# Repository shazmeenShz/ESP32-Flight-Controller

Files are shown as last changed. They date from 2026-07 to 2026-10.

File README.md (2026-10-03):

# ESP32 Flight Controller

<p align="center">
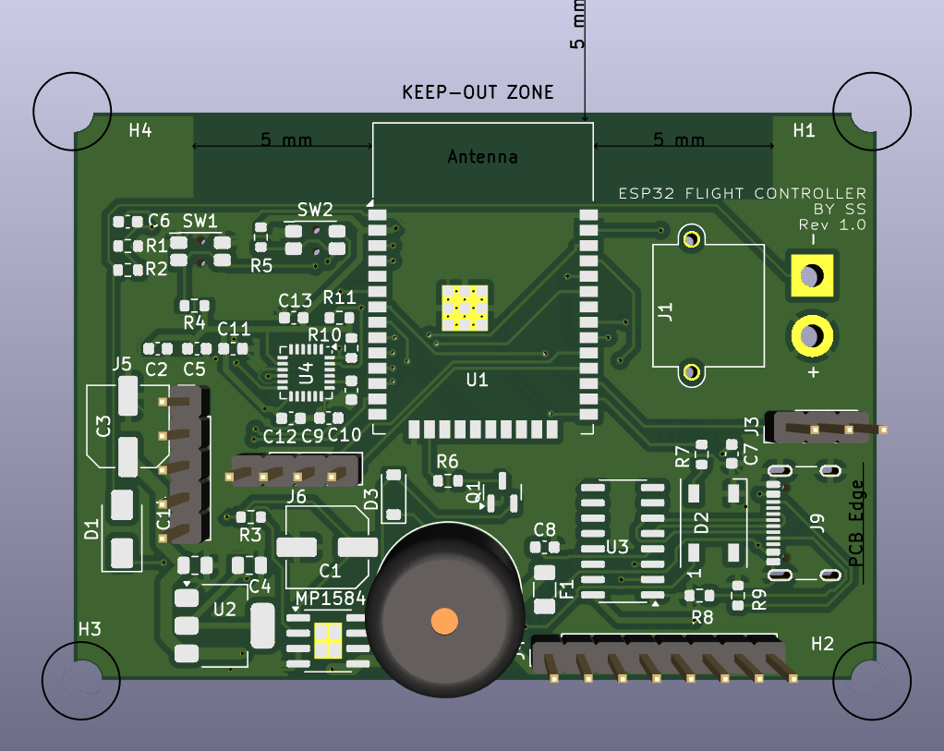
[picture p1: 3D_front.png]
  
</p>

> A custom 4-layer IoT-ready ESP32-based Flight Controller designed in KiCad 8 for UAV and robotics applications.






---

# Overview

This project is a custom-designed 4-layer ESP32-based Flight Controller PCB developed in KiCad 8. Built around the ESP32-WROOM-32E, the board integrates power management, sensor interfaces, USB programming, and wireless connectivity capabilities, making it suitable for UAVs, robotics, and IoT-enabled embedded systems.

The design follows industry-standard PCB practices, including dedicated ground and power planes, RF antenna keep-out, proper decoupling, and comprehensive Design Rule Checking (DRC), resulting in a manufacturing-ready hardware platform.

---

# Applications

- UAV & Drone Flight Controllers
- IoT-enabled Robotics
- Wireless Sensor Nodes
- Remote Monitoring Systems
- Autonomous Embedded Platforms
- Research & Academic Projects
- Rapid Prototyping for Embedded Systems

---

# Features

- ESP32-WROOM-32E Microcontroller
- Wi-Fi & Bluetooth Enabled (ESP32)
- IoT-Ready Embedded Hardware Platform
- 4-Layer PCB Design
- USB Type-C Programming Interface
- CH340C USB-to-UART Converter
- MP1584 Buck Converter (Battery to 5V)
- AMS1117-3.3V Linear Regulator
- MPU6050 6-Axis IMU Interface
- GPS UART Interface
- SBUS/iBUS Receiver Interface
- Battery Voltage Monitoring
- WS2812B Addressable RGB Status LED
- Active Buzzer Interface
- Boot & Reset Buttons
- Mounting Holes
- RF Antenna Keep-Out Zone
- Ground and Power Copper Planes
- DRC Clean (0 Errors, 0 Warnings)

---

# Hardware Specifications

| Parameter | Specification |
|---|---|
| MCU | ESP32-WROOM-32E |
| PCB Layers | 4 |
| Power Input | LiPo Battery |
| Buck Converter | MP1584 |
| LDO Regulator | AMS1117-3.3V |
| USB Interface | USB Type-C |
| USB-UART | CH340C |
| IMU | MPU6050 |
| Receiver | SBUS / iBUS |
| GPS | UART |
| Battery Monitor | Voltage Divider |
| Status Indicator | WS2812B RGB LED |
| Buzzer | Active Buzzer |
| CAD Software | KiCad 8 |

---

# PCB Stack-Up

Layer 1
```
Top Signal Layer
```

Layer 2
```
Ground Plane
```

Layer 3
```
Power Plane
```

Layer 4
```
Bottom Signal Layer
```

---

# Power Architecture

```
LiPo Battery
      │
      ▼
   MP1584
 (Buck Converter)
      │
      ▼
      5V
      │
      ▼
 AMS1117-3.3V
      │
      ▼
     ESP32
```

---

# Interfaces

| Interface | Purpose |
|---|---|
| USB Type-C | Programming & Power |
| UART | GPS |
| SBUS/iBUS | RC Receiver |
| I²C | MPU6050 |
| ADC | Battery Voltage Monitoring |
| GPIO | WS2812B & Buzzer |

---

# Design Highlights

- Dedicated Ground Plane
- Dedicated Power Plane
- RF Antenna Keep-Out
- Proper Decoupling Capacitors
- Copper Pour Optimization
- Manual PCB Routing
- Differential USB Routing
- Professional Silkscreen
- Optimized Component Placement
- Manufacturing Ready

---

# Design Workflow

- Component Selection
- Schematic Design
- ERC Verification
- Footprint Assignment
- PCB Layout
- Component Placement
- Net Class Assignment
- Manual Routing
- Copper Pour
- DRC Verification
- Gerber Generation

---

# Repository Structure

```
ESP32-Flight-Controller
│
├── Hardware
│   ├── flight_controller.kicad_pro
│   ├── flight_controller.kicad_sch
│   ├── flight_controller.kicad_pcb
│
├── Gerbers
│
├── Images
│   ├── PCB_Top.png
│   ├── PCB_Bottom.png
│   ├── 3D_Top.png
│   ├── 3D_Bottom.png
│   └── Schematic.png
│
├── BOM
│
└── README.md
```

---

# Project Status

- [x] Schematic Design
- [x] PCB Layout
- [x] Footprint Assignment
- [x] 4-Layer PCB
- [x] Manual Routing
- [x] Ground Copper Pour
- [x] Power Copper Plane
- [x] DRC Passed
- [x] Manufacturing Ready

---

# Images

## PCB Layout

<p align="center">
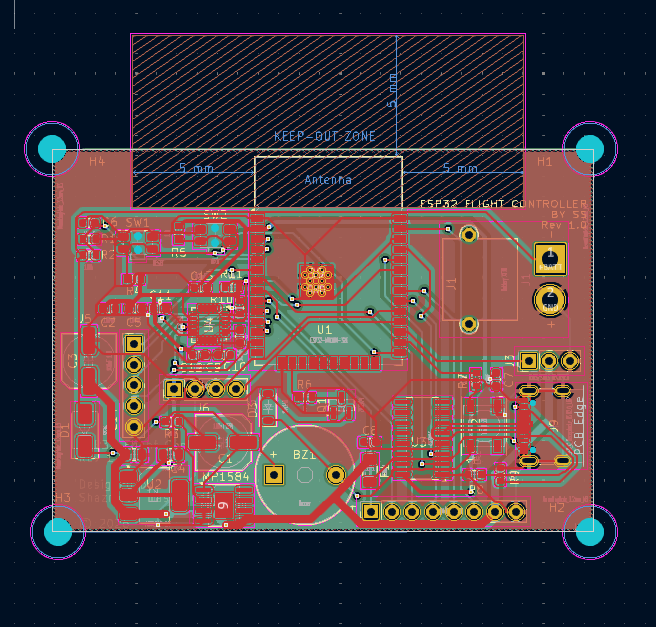
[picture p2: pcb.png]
  
</p>

---

## 3D View

<p align="center">
  
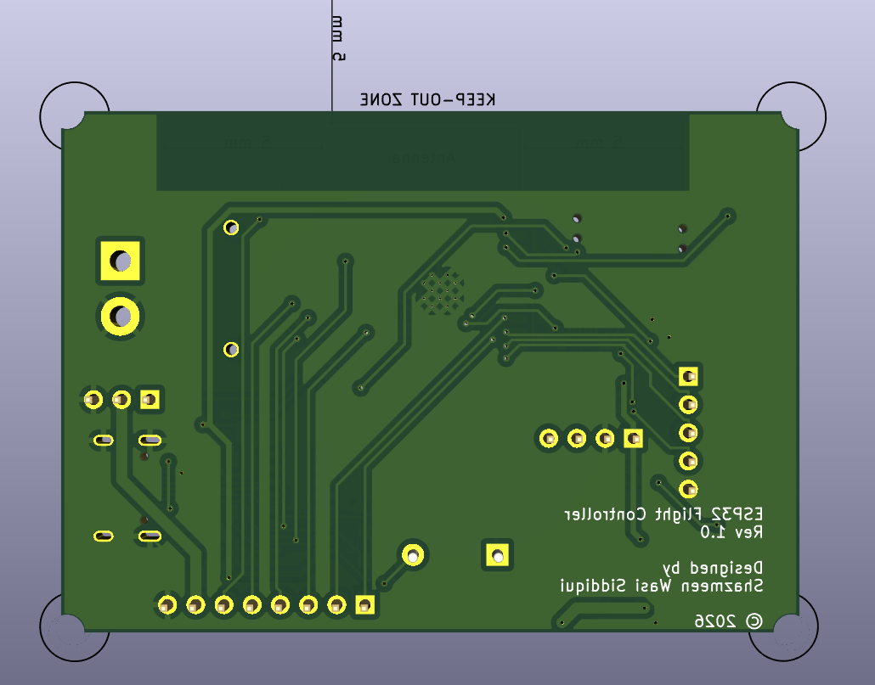
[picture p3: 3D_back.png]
  
</p>

---

## Schematic

<p align="center">
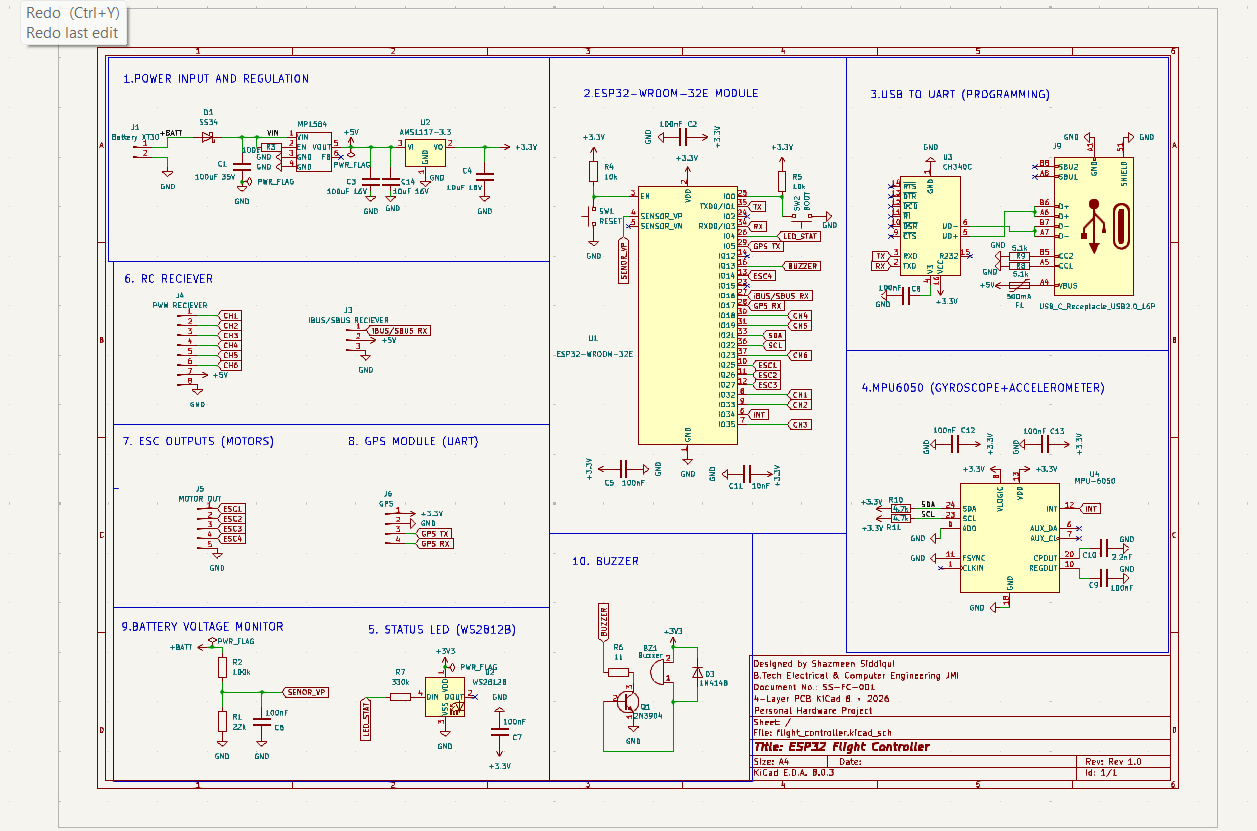
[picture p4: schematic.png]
  
</p>

---

# Future Improvements

- BMP280/BME280 Barometer
- Magnetometer Support
- Current Sensor
- Blackbox Logging
- CAN Interface
- ESD Protection
- Reverse Polarity Protection

---

# Hardware Revisions

## Rev 1

The original ESP32 Flight Controller hardware design is maintained in the root of this repository. It represents the first manufactured prototype of the project.

## Rev 2

Rev 2 is the second hardware revision of the ESP32 Flight Controller. The complete Rev 2 design and manufacturing files are provided under the `Rev2/` directory.

### Rev 2 Contents

- KiCad schematic and PCB design files
- Gerber manufacturing files
- Bill of Materials (BOM)
- Drill files and manufacturing documentation
- PCB images and photographs

### Manufacturing Support

<p align="center">
  
</p>

A sincere thank you to NextPCB for supporting the manufacturing of the Rev 2 PCB.

Their support helped me take the design from KiCad to a professionally manufactured board and continue the hands-on testing and development of the project.

I truly appreciate NextPCB for supporting student-led, open-source hardware projects and making opportunities like this possible.

**Manufacturing Partner:** NextPCB  
**Sponsored Revision:** Rev 2

---

## Rev 2 Repository Structure

```text
Rev2/
├── KiCad/
├── Gerbers/
├── BOM/
├── Documentation/
└── Images/

# Tools Used

- KiCad 8
- ESP32-WROOM-32E
- CH340C
- MP1584
- AMS1117
- MPU6050

---

# Author

**Designed & Developed by**

**Shazmeen Wasi Siddiqui**

B.Tech — Electrical & Computer Engineering

Jamia Millia Islamia

---

# License

This project is released under the **MIT License**.

---

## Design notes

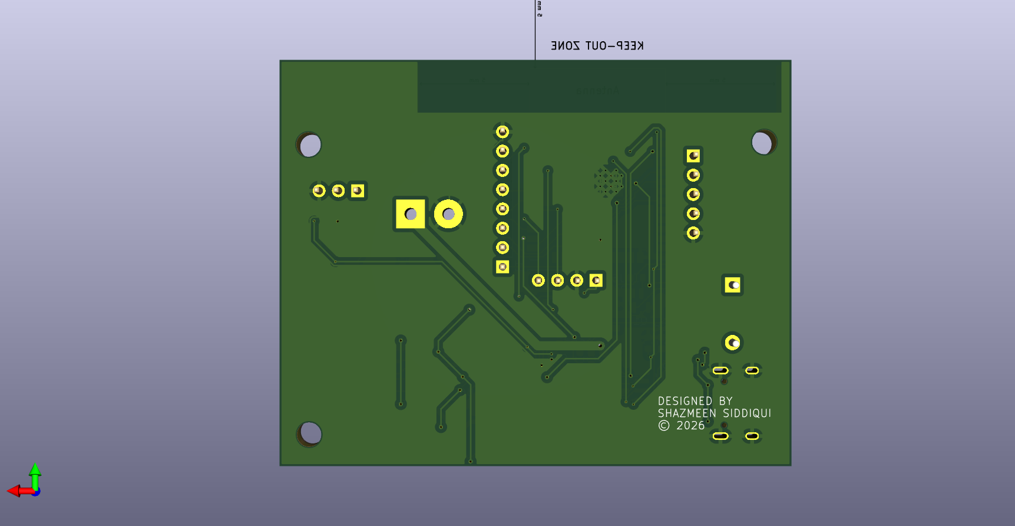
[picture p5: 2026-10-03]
Rev2/Images/flight_controller_rev2_back.png

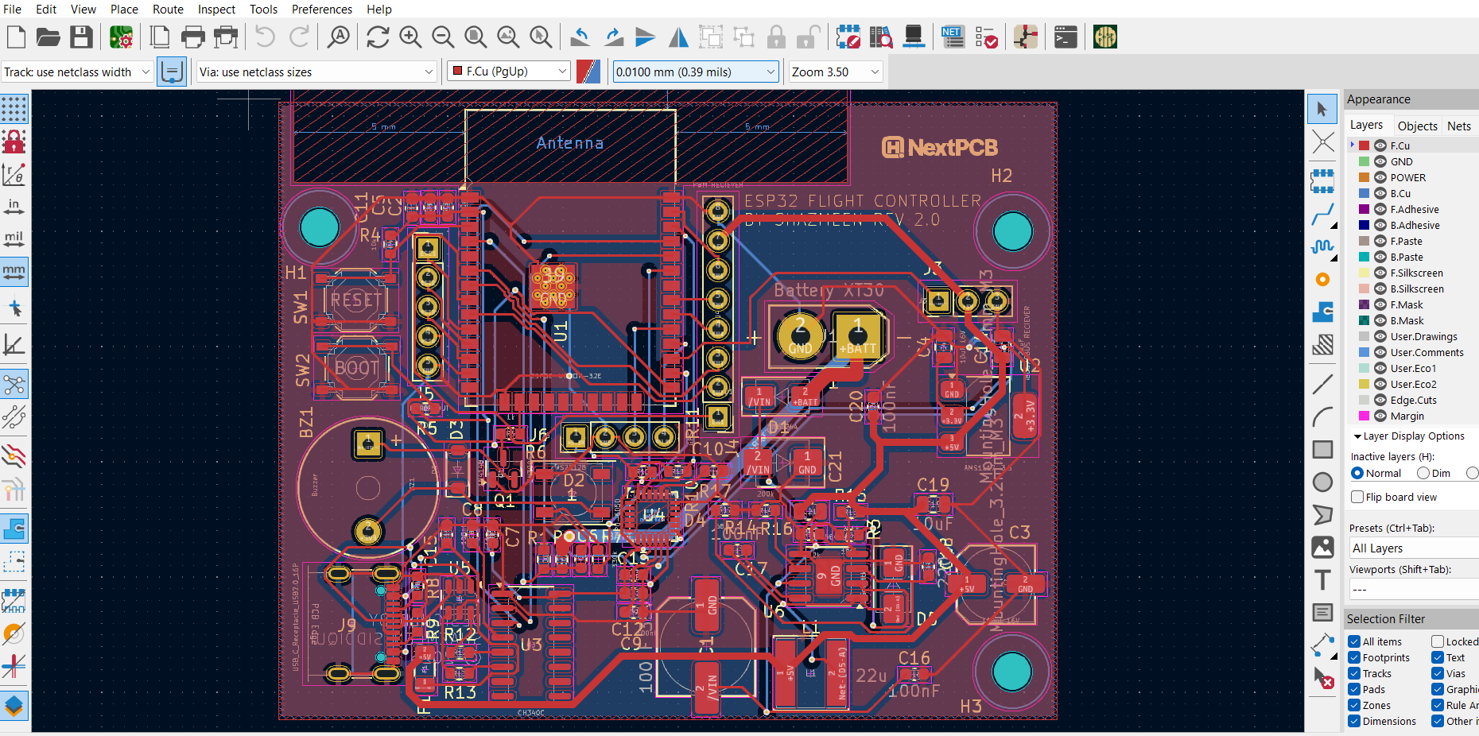
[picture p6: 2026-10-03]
Rev2/Images/{EEBD7A86-BAF1-454D-B3C5-F652BD7458B7}.png

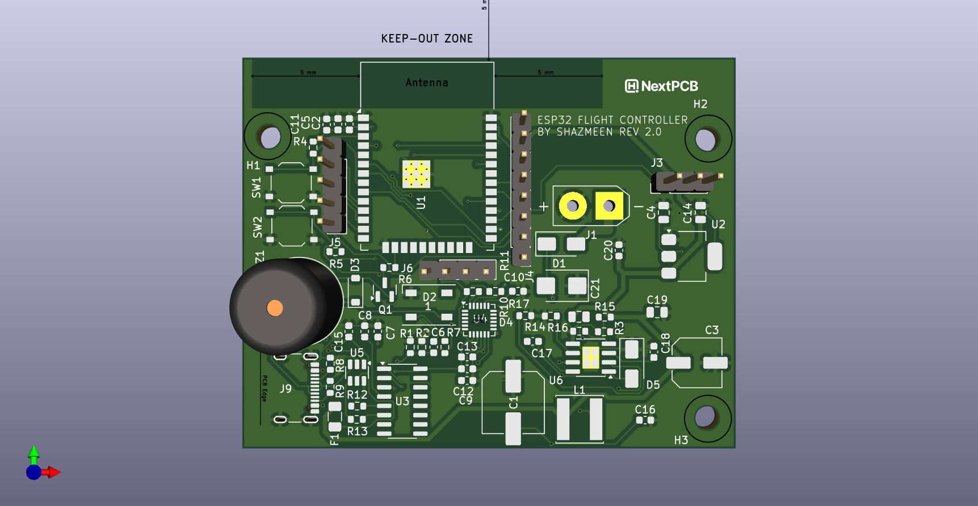
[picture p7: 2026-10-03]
Rev2/Images/flight_controller_rev2.png

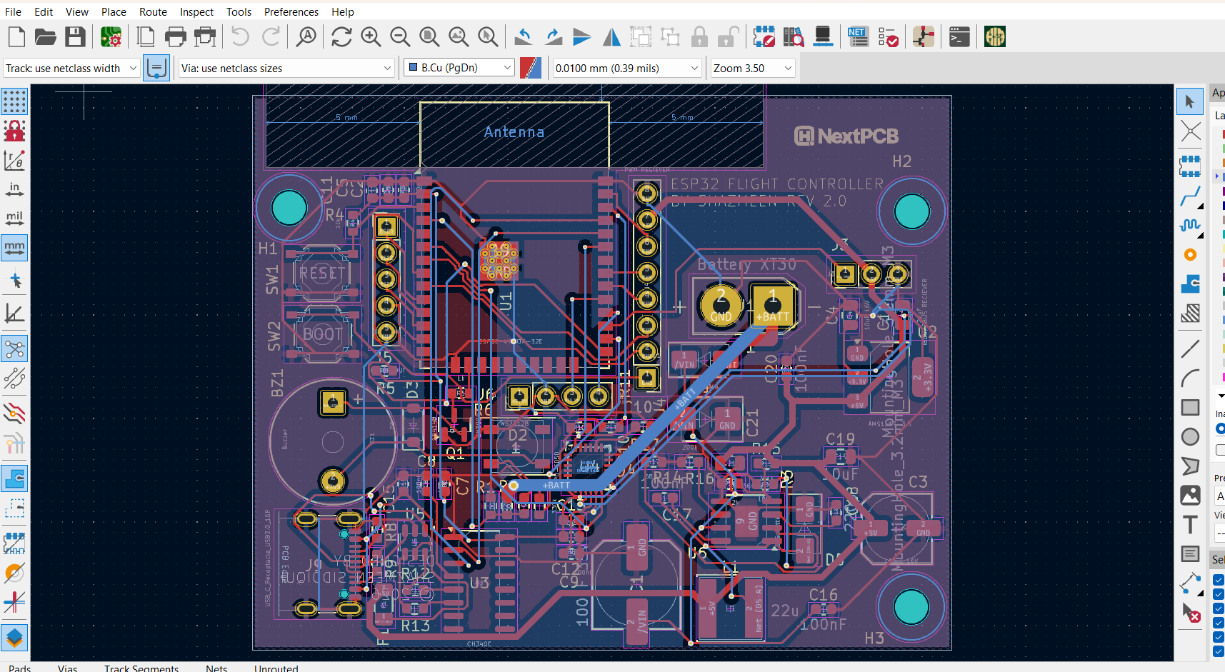
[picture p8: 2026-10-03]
Rev2/Images/{7333D2C4-E5C4-4866-A92E-B36D244C8C60}.png

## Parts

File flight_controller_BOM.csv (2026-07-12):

Reference | Value | Datasheet | Footprint | Qty | DNP
BZ1 | Buzzer | ~ | Buzzer_Beeper:Buzzer_12x9.5RM7.6 | 1
C1 | 100uF 35V | ~ | Capacitor_SMD:C_Elec_6.3x5.8 | 1
C2,C5,C6,C7,C8,C9,C12,C13 | 100nF | ~ | Capacitor_SMD:C_0603_1608Metric | 8
C3 | 100uF 16V | ~ | Capacitor_SMD:C_Elec_6.3x5.8 | 1
C4,C14 | 10uF 16V | ~ | Capacitor_SMD:C_0805_2012Metric | 2
C10 | 2.2nF | ~ | Capacitor_SMD:C_0603_1608Metric | 1
C11 | 10nF | ~ | Capacitor_SMD:C_0603_1608Metric | 1
D1 | SS34 | https://www.vishay.com/docs/88751/ss32.pdf | Diode_SMD:D_SMA | 1
D2 | WS2812B | https://cdn-shop.adafruit.com/datasheets/WS2812B.pdf | LED_SMD:LED_WS2812B_PLCC4_5.0x5.0mm_P3.2mm | 1
D3 | 1N4148 | https://assets.nexperia.com/documents/data-sheet/1N4148_1N4448.pdf | Diode_SMD:D_SOD-123 | 1
F1 | 500mA | ~ | Fuse:Fuse_1206_3216Metric | 1
J1 | Battery XT30 | ~ | Connector_AMASS:AMASS_XT30PW-M_1x02_P2.50mm_Horizontal | 1
J3 | IBUS/SBUS RECIEVER | ~ | Connector_PinHeader_2.54mm:PinHeader_1x03_P2.54mm_Vertical | 1
J4 | PWM RECIEVER | ~ | Connector_PinHeader_2.54mm:PinHeader_1x08_P2.54mm_Vertical | 1
J5 | MOTOR OUT | ~ | Connector_PinHeader_2.54mm:PinHeader_1x05_P2.54mm_Vertical | 1
J6 | GPS | ~ | Connector_PinHeader_2.54mm:PinHeader_1x04_P2.54mm_Vertical | 1
J9 | USB_C_Receptacle_USB2.0_16P | https://www.usb.org/sites/default/files/documents/usb_type-c.zip | Connector_USB:USB_C_Receptacle_GCT_USB4105-xx-A_16P_TopMnt_Horizontal | 1
MP1584 | ~ |  | Package_SO:SOIC-8-1EP_3.9x4.9mm_P1.27mm_EP2.29x3mm | 1
Q1 | 2N3904 | https://www.onsemi.com/pub/Collateral/2N3903-D.PDF | Package_TO_SOT_SMD:SOT-23 | 1
R1 | 22k | ~ | Resistor_SMD:R_0603_1608Metric | 1
R2,R3 | 100k | ~ | Resistor_SMD:R_0603_1608Metric | 2
R4,R5 | 10k | ~ | Resistor_SMD:R_0603_1608Metric | 2
R6 | 1k | ~ | Resistor_SMD:R_0603_1608Metric | 1
R7 | 330k | ~ | Resistor_SMD:R_0603_1608Metric | 1
R8,R9 | 5.1k | ~ | Resistor_SMD:R_0603_1608Metric | 2
R10,R11 | 4.7k | ~ | Resistor_SMD:R_0603_1608Metric | 2
SW1 | RESET | ~ | Button_Switch_SMD:SW_SPST_EVQP7C | 1
SW2 | BOOT | ~ | Button_Switch_SMD:SW_SPST_EVQP7C | 1
U1 | ESP32-WROOM-32E | https://www.espressif.com/sites/default/files/documentation/esp32-wroom-32e_esp32-wroom-32ue_datasheet_en.pdf | RF_Module:ESP32-WROOM-32D | 1
U2 | AMS1117-3.3 | http://www.advanced-monolithic.com/pdf/ds1117.pdf | Package_TO_SOT_SMD:SOT-223-3_TabPin2 | 1
U3 | CH340C | https://datasheet.lcsc.com/szlcsc/Jiangsu-Qin-Heng-CH340C_C84681.pdf | Package_SO:SOIC-16_3.9x9.9mm_P1.27mm | 1
U4 | MPU-6050 | https://invensense.tdk.com/wp-content/uploads/2015/02/MPU-6000-Datasheet1.pdf | Sensor_Motion:InvenSense_QFN-24_4x4mm_P0.5mm | 1

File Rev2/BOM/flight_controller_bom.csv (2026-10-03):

Reference | Value | Datasheet | Footprint | Qty | DNP | MP | DESCRIPTION | MF
BZ1 | Buzzer | ~ | Buzzer_Beeper:Buzzer_12x9.5RM7.6 | 1
C1 | 100uF 35V | ~ | Capacitor_SMD:C_Elec_6.3x5.8 | 1
C2,C5,C6,C7,C8,C9,C12,C13,C15,C16,C17,C20 | 100nF | ~ | -- mixed values -- | 12
C3 | 100uF 16V | ~ | Capacitor_SMD:C_Elec_6.3x5.8 | 1
C4 | 10uF 16V | ~ | Capacitor_SMD:C_0805_2012Metric | 1
C10 | 2.2nF | ~ | Capacitor_SMD:C_0603_1608Metric | 1
C11 | 10nF | ~ | Capacitor_SMD:C_0603_1608Metric | 1
C14 | 22uF | ~ | Capacitor_SMD:C_0805_2012Metric | 1
C18 | 220p | ~ | Capacitor_SMD:C_0805_2012Metric | 1
C19,C21 | 10uF | ~ | -- mixed values -- | 2
D1 | SS34 | https://www.vishay.com/docs/88751/ss32.pdf | Diode_SMD:D_SMA | 1
D2 | WS2812B | https://cdn-shop.adafruit.com/datasheets/WS2812B.pdf | LED_SMD:LED_WS2812B_PLCC4_5.0x5.0mm_P3.2mm | 1
D3 | 1N4148 | https://assets.nexperia.com/documents/data-sheet/1N4148_1N4448.pdf | Diode_SMD:D_SOD-123 | 1
D4 | SM6T24A | https://www.st.com/resource/en/datasheet/sm6t.pdf | Diode_SMD:D_SMB | 1
D5 | D_Schottky | ~ | Diode_SMD:D_SMA | 1
F1 | 500mA | ~ | Fuse:Fuse_1206_3216Metric | 1
J1 | Battery XT30 | ~ | Connector_AMASS:AMASS_XT30PW-M_1x02_P2.50mm_Horizontal | 1
J3 | IBUS/SBUS RECIEVER | ~ | Connector_PinHeader_2.54mm:PinHeader_1x03_P2.54mm_Vertical | 1
J4 | PWM RECIEVER | ~ | Connector_PinHeader_2.54mm:PinHeader_1x08_P2.54mm_Vertical | 1
J5 | MOTOR OUT | ~ | Connector_PinHeader_2.54mm:PinHeader_1x05_P2.54mm_Vertical | 1
J6 | GPS | ~ | Connector_PinHeader_2.54mm:PinHeader_1x04_P2.54mm_Vertical | 1
J9 | USB_C_Receptacle_USB2.0_16P | https://www.usb.org/sites/default/files/documents/usb_type-c.zip | Connector_USB:USB_C_Receptacle_GCT_USB4105-xx-A_16P_TopMnt_Horizontal | 1
L1 | 22u | ~ | Inductor_SMD:L_7.3x7.3_H3.5 | 1
Q1 | 2N3904 | https://www.onsemi.com/pub/Collateral/2N3903-D.PDF | Package_TO_SOT_SMD:SOT-23 | 1
R1 | 22k | ~ | Resistor_SMD:R_0603_1608Metric | 1
R2,R3 | 100k | ~ | Resistor_SMD:R_0603_1608Metric | 2
R4,R5 | 10k | ~ | Resistor_SMD:R_0603_1608Metric | 2
R6 | 1k | ~ | Resistor_SMD:R_0603_1608Metric | 1
R7 | 330k | ~ | Resistor_SMD:R_0603_1608Metric | 1
R8,R9 | 5.1k | ~ | Resistor_SMD:R_0603_1608Metric | 2
R10,R11 | 4.7k | ~ | Resistor_SMD:R_0603_1608Metric | 2
R12,R13 | 22 | ~ | Resistor_SMD:R_0603_1608Metric | 2
R14 | 200k | ~ | Resistor_SMD:R_0603_1608Metric | 1
R15 | 211k | ~ | Resistor_SMD:R_0603_1608Metric | 1
R16 | 40.2k | ~ | Resistor_SMD:R_0603_1608Metric | 1
R17 | 68.1k | ~ | Resistor_SMD:R_0603_1608Metric | 1
SW1 | RESET | ~ | Button_Switch_SMD:SW_SPST_EVQP7C | 1
SW2 | BOOT | ~ | Button_Switch_SMD:SW_SPST_EVQP7C | 1
U1 | ESP32-WROOM-32E | https://www.espressif.com/sites/default/files/documentation/esp32-wroom-32e_esp32-wroom-32ue_datasheet_en.pdf | RF_Module:ESP32-WROOM-32D | 1
U2 | AMS1117-3.3 | http://www.advanced-monolithic.com/pdf/ds1117.pdf | Package_TO_SOT_SMD:SOT-223-3_TabPin2 | 1
U3 | CH340C | https://datasheet.lcsc.com/szlcsc/Jiangsu-Qin-Heng-CH340C_C84681.pdf | Package_SO:SOIC-16_3.9x9.9mm_P1.27mm | 1
U4 | MPU-6050 | https://invensense.tdk.com/wp-content/uploads/2015/02/MPU-6000-Datasheet1.pdf | Sensor_Motion:InvenSense_QFN-24_4x4mm_P0.5mm | 1
U5 | USBLC6-2SC6 | https://www.st.com/resource/en/datasheet/usblc6-2.pdf | Package_TO_SOT_SMD:SOT-23-6 | 1
U6 | MP1584EN |  | Package_SO:SOIC-8-1EP_3.9x4.9mm_P1.27mm_EP2.29x3mm | 1 |  | MP1584EN |  | Monolithic Power Systems

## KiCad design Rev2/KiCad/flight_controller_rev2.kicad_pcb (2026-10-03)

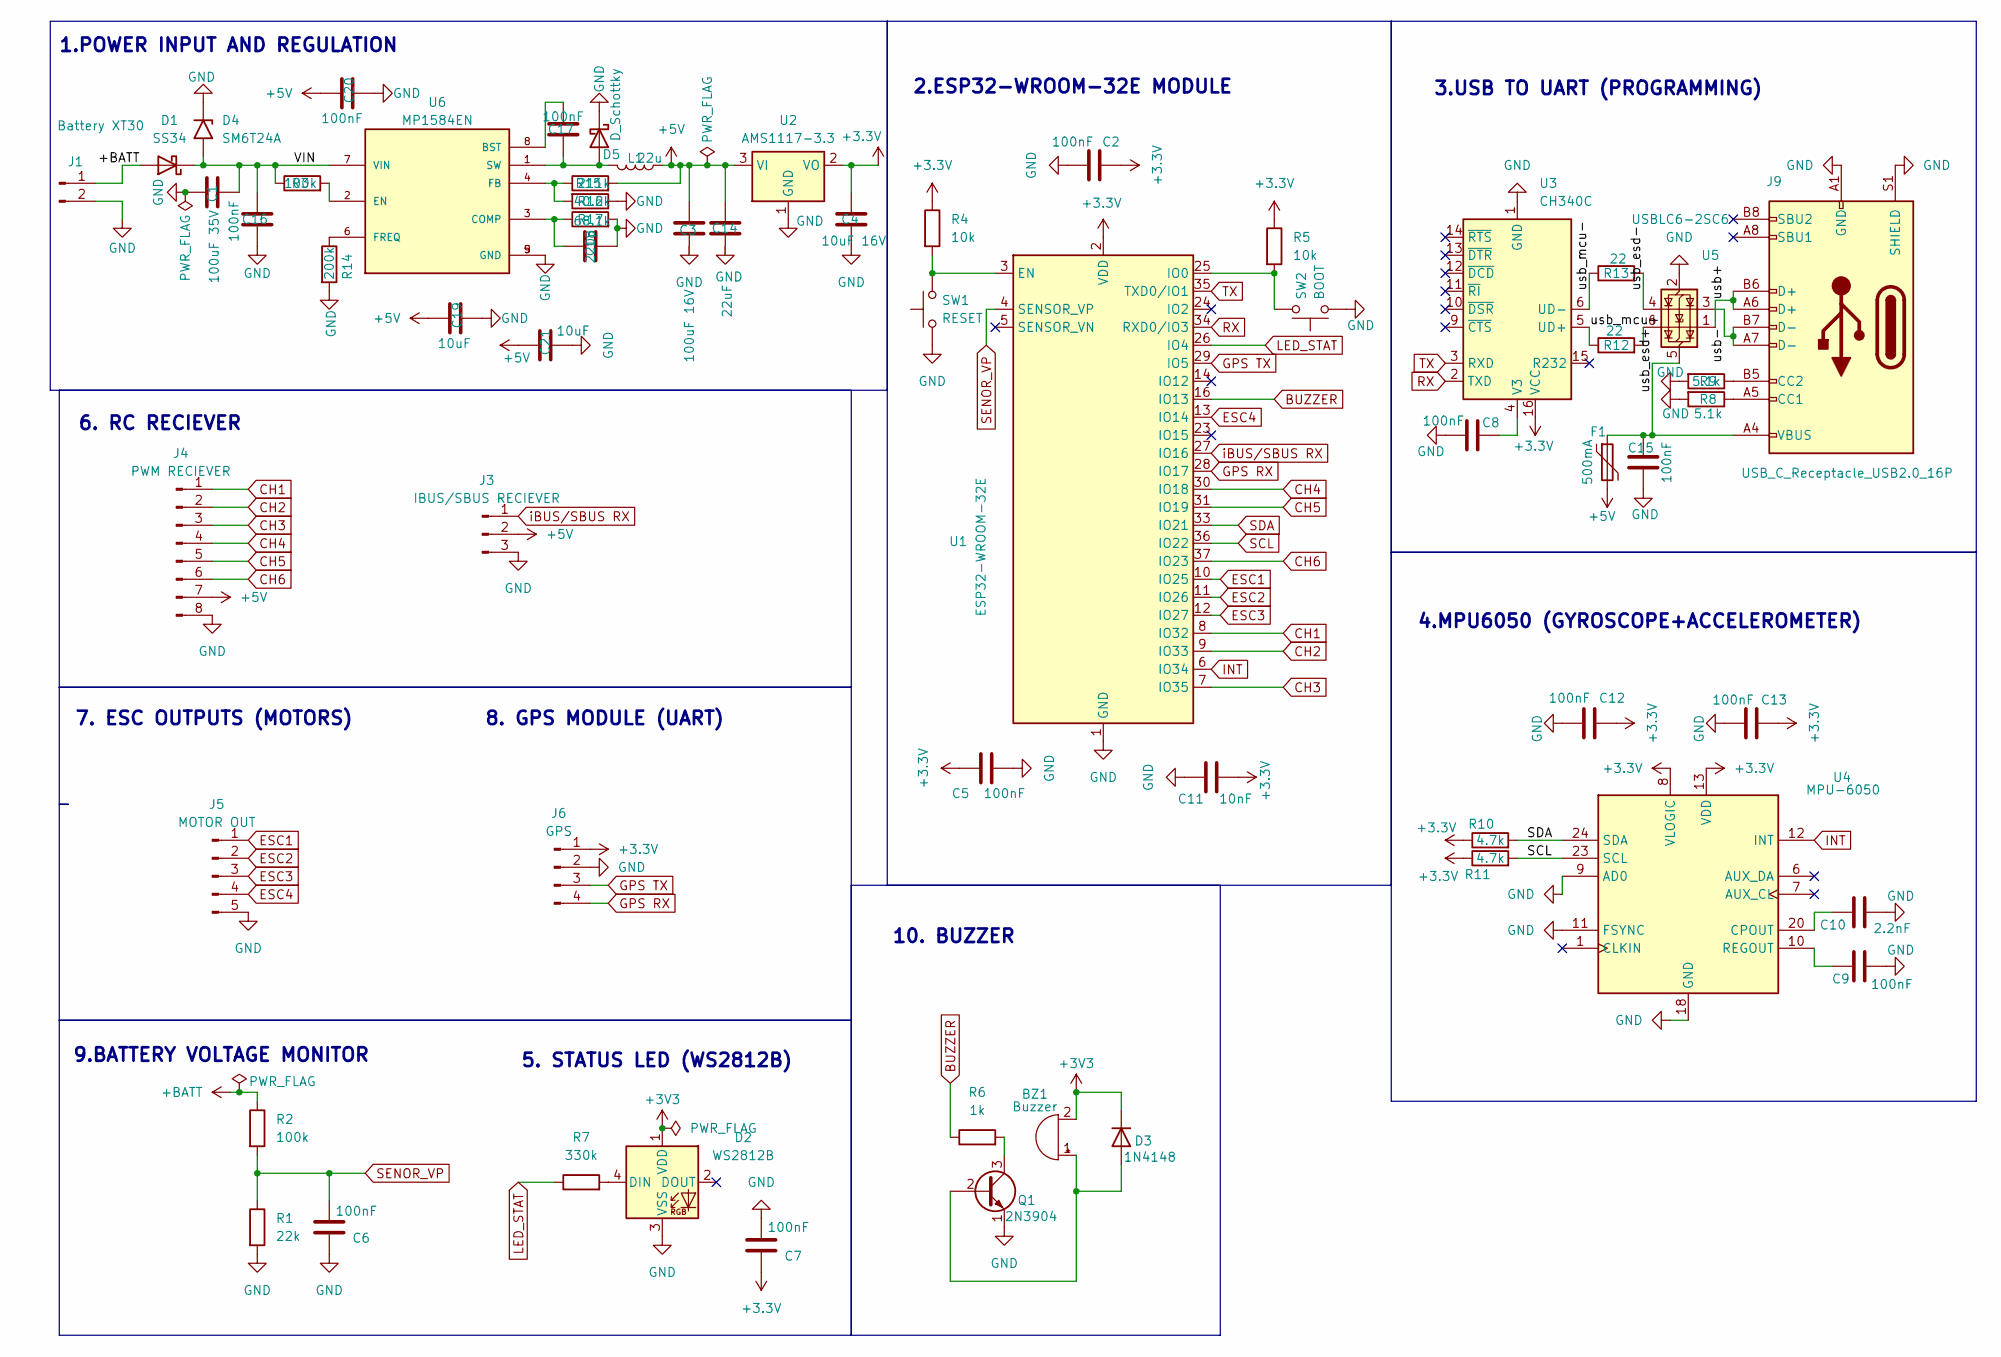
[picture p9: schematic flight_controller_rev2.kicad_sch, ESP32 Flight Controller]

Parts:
BZ1: Buzzer; Buzzer_12x9.5RM7.6
C1: 100uF 35V; C_Elec_8x10.2
C2, C5, C6, C7, C8, C9, C12, C13, C15, C16, C17, C20: 100nF; C_0603_1608Metric
C3: 100uF 16V; C_Elec_6.3x5.8
C4: 10uF 16V; C_0805_2012Metric
C10: 2.2nF; C_0603_1608Metric
C11: 10nF; C_0603_1608Metric
C14: 22uF; C_0805_2012Metric
C18: 220p; C_0603_1608Metric
C19, C21: 10uF; C_0805_2012Metric
D1: SS34; D_SMA
D2: WS2812B; LED_WS2812B_PLCC4_5.0x5.0mm_P3.2mm
D3: 1N4148; D_SOD-123
D4: SM6T24A; D_SMB
D5: D_Schottky; D_SMA
F1: 500mA; Fuse_1206_3216Metric
J1: Battery XT30; AMASS_XT30U-M_1x02_P5.0mm_Vertical
J3: IBUS/SBUS RECIEVER; PinHeader_1x03_P2.54mm_Vertical
J4: PWM RECIEVER; PinHeader_1x08_P2.54mm_Vertical
J5: MOTOR OUT; PinHeader_1x05_P2.54mm_Vertical
J6: GPS; PinHeader_1x04_P2.54mm_Vertical
J9: USB_C_Receptacle_USB2.0_16P; USB_C_Receptacle_GCT_USB4105-xx-A_16P_TopMnt_Horizontal
L1: 22u; L_Sunlord_SWPA6028S
Q1: 2N3904; SOT-23
R1: 22k; R_0603_1608Metric
R2, R3: 100k; R_0603_1608Metric
R4, R5: 10k; R_0603_1608Metric
R6: 1k; R_0603_1608Metric
R7: 330k; R_0603_1608Metric
R8, R9: 5.1k; R_0603_1608Metric
R10, R11: 4.7k; R_0603_1608Metric
R12, R13: 22; R_0603_1608Metric
R14: 200k; R_0603_1608Metric
R15: 211k; R_0603_1608Metric
R16: 40.2k; R_0603_1608Metric
R17: 68.1k; R_0603_1608Metric
SW1: RESET; SW_Push_1P1T_XKB_TS-1187A
SW2: BOOT; SW_Push_1P1T_XKB_TS-1187A
U1: ESP32-WROOM-32E; ESP32-WROOM-32D
U2: AMS1117-3.3; SOT-223-3_TabPin2
U3: CH340C; SOIC-16_3.9x9.9mm_P1.27mm
U4: MPU-6050; InvenSense_QFN-24_4x4mm_P0.5mm
U5: USBLC6-2SC6; SOT-23-6
U6: MP1584EN; SOIC-8-1EP_3.9x4.9mm_P1.27mm_EP2.29x3mm

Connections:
+3.3V: C2.1, C4.1, C5.1, C7.1, C11.1, C12.1, C13.1, J6.1, R4.1, R5.1, R10.1, R11.1, U1.2 (VDD), U2.2 (VO), U3.16 (VCC), U4.8 (VLOGIC), U4.13 (VDD)
+3V3: BZ1.2 (-), D2.1 (VDD), D3.1 (K)
+5V: C3.1, C14.1, C19.1, C20.1, C21.1, F1.2, J3.2, J4.7, L1.1, R15.2, U2.3 (VI)
+BATT: D1.2 (A), J1.1, R2.1
/VIN: C1.2, C16.1, D1.1 (K), D4.2 (A2), R3.1, U6.7 (VIN)
/usb+: J9.A6 (D+), J9.B6 (D+), U5.1 (I/O1)
/usb-: J9.A7 (D-), J9.B7 (D-), U5.3 (I/O2)
/usb_esd-: R13.2, U5.4 (I/O2)
/usb_mcu+: R12.1, U3.5 (UD+)
/usb_mcu-: R13.1, U3.6 (UD-)
BUZZER: R6.1, U1.16 (IO13)
CH1: J4.1, U1.8 (IO32)
CH2: J4.2, U1.9 (IO33)
CH3: J4.3, U1.7 (IO35)
CH4: J4.4, U1.30 (IO18)
CH5: J4.5, U1.31 (IO19)
CH6: J4.6, U1.37 (IO23)
ESC1: J5.1, U1.10 (IO25)
ESC2: J5.2, U1.11 (IO26)
ESC3: J5.3, U1.12 (IO27)
ESC4: J5.4, U1.13 (IO14)
GND: C1.1, C2.2, C3.2, C4.2, C5.2, C6.1, C7.2, C8.2, C9.2, C10.2, C11.2, C12.2, C13.2, C14.2, C15.2, C16.2, C18.2, C19.2, C20.2, C21.2, D2.3 (VSS), D4.1 (A1), D5.1 (K), J1.2, J3.3, J4.8, J5.5, J6.2, J9.A1 (GND), J9.A12 (GND), J9.B1 (GND), J9.B12 (GND), J9.S1 (SHIELD), Q1.1 (E), R1.2, R8.2, R9.2, R14.2, R16.1, R17.2, SW1.1, SW2.1, U1.1 (GND), U1.15 (GND), U1.38 (GND), U1.39 (GND), U2.1 (GND), U3.1 (GND), U4.9 (AD0), U4.11 (FSYNC), U4.18 (GND), U5.2 (GND), U6.5 (GND), U6.9 (GND)
GPS RX: J6.4, U1.28 (IO17)
GPS TX: J6.3, U1.29 (IO5)
INT: U1.6 (IO34), U4.12 (INT)
LED_STAT: R7.1, U1.26 (IO4)
unnamed: BZ1.1 (+), D3.2 (A), Q1.2 (B)
unnamed: D2.4 (DIN), R7.2
unnamed: C17.2, D5.2 (A), L1.2, U6.1 (SW)
unnamed: J9.A5 (CC1), R8.1
unnamed: J9.B5 (CC2), R9.1
unnamed: Q1.3 (C), R6.2
unnamed: R12.2, U5.6 (I/O1)
unnamed: R4.2, SW1.2, U1.3 (EN)
unnamed: R5.2, SW2.2, U1.25 (IO0)
unnamed: C8.1, U3.4 (V3)
unnamed: C10.1, U4.20 (CPOUT)
unnamed: C9.1, U4.10 (REGOUT)
unnamed: C15.1, F1.1, J9.A4 (VBUS), J9.A9 (VBUS), J9.B4 (VBUS), J9.B9 (VBUS), U5.5 (VBUS)
unnamed: C17.1, U6.8 (BST)
unnamed: C18.1, R17.1, U6.3 (COMP)
unnamed: R3.2, U6.2 (EN)
unnamed: R15.1, R16.2, U6.4 (FB)
unnamed: R14.1, U6.6 (FREQ)
RX: U1.34 (RXD0/IO3), U3.2 (TXD)
SCL: R11.2, U1.36 (IO22), U4.23 (SCL)
SDA: R10.2, U1.33 (IO21), U4.24 (SDA)
SENOR_VP: C6.2, R1.1, R2.2, U1.4 (SENSOR_VP)
TX: U1.35 (TXD0/IO1), U3.3 (RXD)
iBUS/SBUS RX: J3.1, U1.27 (IO16)

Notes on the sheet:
7. ESC OUTPUTS (MOTORS)
9.BATTERY VOLTAGE MONITOR
2.ESP32-WROOM-32E MODULE
3.USB TO UART (PROGRAMMING)
10. BUZZER
4.MPU6050 (GYROSCOPE+ACCELEROMETER)
6. RC RECIEVER
8. GPS MODULE (UART)
5. STATUS LED (WS2812B)
1.POWER INPUT AND REGULATION

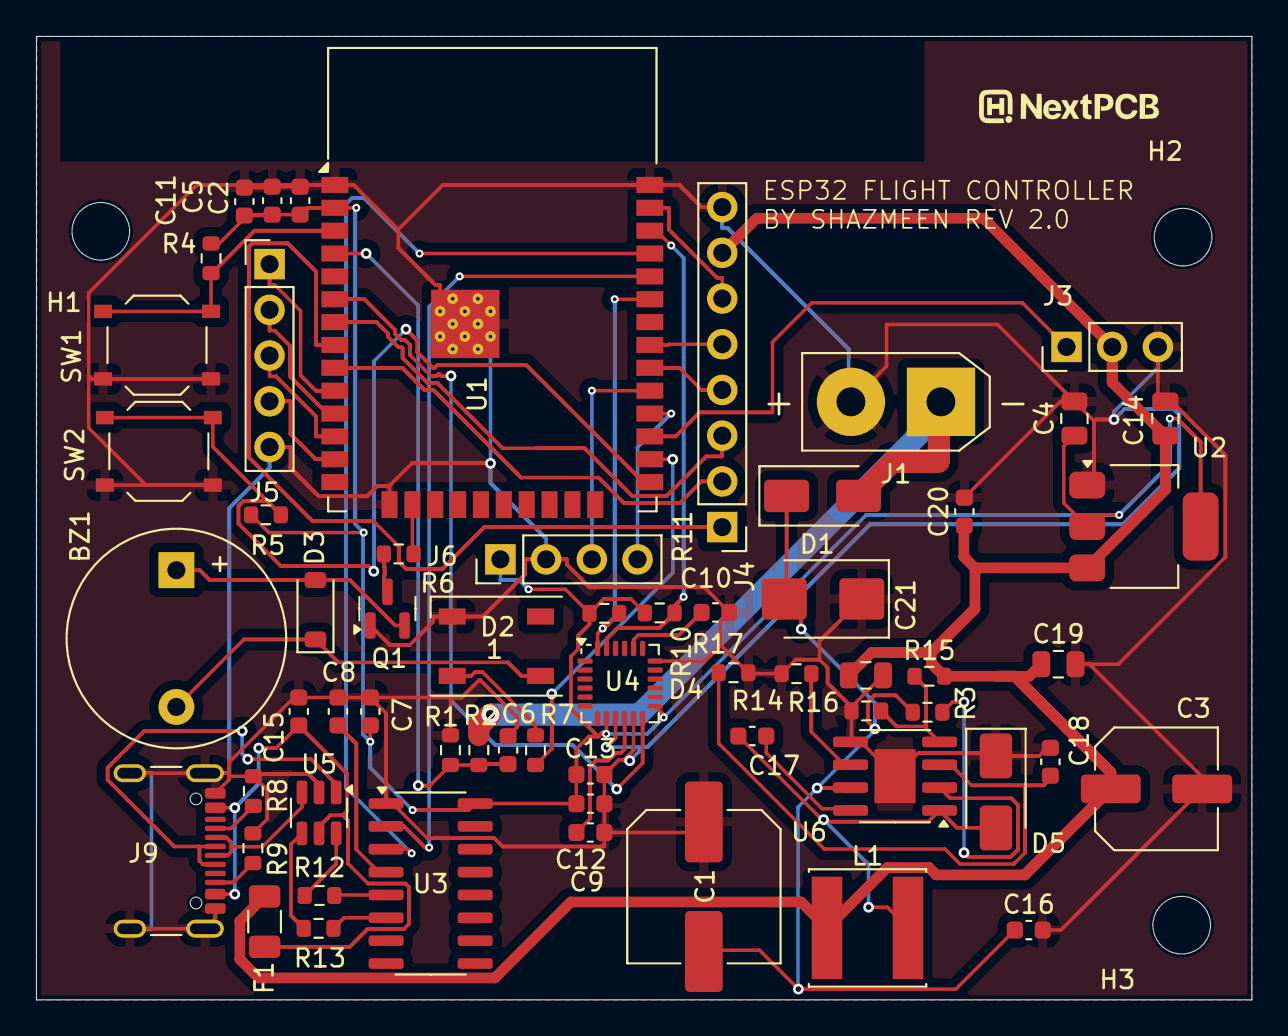
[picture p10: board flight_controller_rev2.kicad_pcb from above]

Board: 4 copper layers, 67.5 x 53.5 mm, 64 parts (0 on the bottom side), 50 nets.

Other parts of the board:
H1, H2, H3: MountingHole_3.2mm_M3

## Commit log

2026-07-12 Revise README for ESP32 Flight Controller project
    Updated project title and added detailed project overview, features, specifications, and design highlights. Included repository structure and project status sections for better clarity.
2026-07-12 Revise PCB layout section and add image placeholders
    Updated PCB section headings and added image placeholders.
2026-10-03 Add Rev 2 hardware design
    [flight_controller_rev2.kicad_pcb, flight_controller_rev2.kicad_sch]
2026-10-03 Add Rev 2 manufacturing files
    [flight_controller_bom.csv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]
2026-10-20 Rename WhatsApp Image 2026-09-08 at 21.58.56.jpeg to pcb_in_hand
2026-10-20 Rename WhatsApp Image 2026-09-08 at 21.58.57.jpeg to pcb_closeup
2026-10-20 Rename WhatsApp Image 2026-09-08 at 22.02.03.jpeg to pcb_back_side

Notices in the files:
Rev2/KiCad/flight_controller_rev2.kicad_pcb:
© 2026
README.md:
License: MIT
